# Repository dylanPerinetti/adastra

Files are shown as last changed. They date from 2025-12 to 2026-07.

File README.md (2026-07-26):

# ADASTRA - Data Logger V2 Fusee

### Club NOVA CNAM - CSPACE 2026

Electronique embarquee pour la fusee experimentale du **club NOVA CNAM**, dans le cadre du projet **ADASTRA**.

Le systeme est compose de **deux Arduino Nano independants** :

| Arduino | Role | Fichier source |
|---|---|---|
| **Arduino #1 – Data Logger** | Acquisition capteurs + enregistrement CSV sur micro-SD | `adastra_datalogger-v2.ino` |
| **Arduino #2 – Sequenceur** | Declenchement parachute (solenoide + ressort) | `Sequenceur_Nano.ino` |

---

## Arborescence du depot

```text
adastra/
├── src/
│   ├── adastra_datalogger-v2.ino   # Arduino #1 – Data logger micro-SD
│   ├── Sequenceur_Nano.ino         # Arduino #2 – Sequenceur parachute
│   └── Sequenceur.md               # Documentation sequenceur
│
├── analysis/
│   └── analyse_vol.py              # Analyse post-vol (Python)
│
├── docs/
│   └── schema_branchement.png      # Schema de cablage
│
└── README.md
```

---

## Materiel

### Arduino #1 – Data Logger

| Composant | Role |
|---|---|
| **Arduino Nano** | Microcontroleur data logger |
| **MPU6050** | Accelerometre + gyroscope 6 axes (I2C) |
| **BMP280** | Pression, altitude, temperature (I2C) |
| **HC-SR04** | Capteur ultrason - distance sol (digital) |
| **Module micro-SD (SPI)** | Stockage des donnees de vol |

### Arduino #2 – Sequenceur parachute

| Composant | Role |
|---|---|
| **Arduino Nano** | Microcontroleur sequenceur |
| **Solenoide 24 V** | Liberation du verrou de trappe |
| **MOSFET N logic-level** (IRLZ44N) | Commande de puissance solenoide |
| **Jack de rampe** | Detection decollage (arrachement) |
| **LEDs** | Indication d'etat (arme / tempo / fire / done) |
| **Diode de roue libre** (1N5408) | Protection bobine solenoide |

> Voir [src/Sequenceur.md](src/Sequenceur.md) pour le detail du sequenceur.

---

## Branchement

### Bus I2C (MPU6050 + BMP280)

| Arduino Nano | Module |
|---|---|
| A4 (SDA) | SDA MPU6050 / BMP280 |
| A5 (SCL) | SCL MPU6050 / BMP280 |

### MPU6050

| MPU6050 | Arduino Nano |
|---|---|
| VCC | 5 V *(ou 3.3 V selon module)* |
| GND | GND |
| SDA | A4 |
| SCL | A5 |

Adresse I2C : `0x68`

### BMP280

| BMP280 | Arduino Nano |
|---|---|
| VCC | 3.3 V |
| GND | GND |
| SDA | A4 |
| SCL | A5 |

Adresse I2C : `0x76`

### HC-SR04

| HC-SR04 | Arduino Nano |
|---|---|
| VCC | 5 V |
| GND | GND |
| TRIG | D2 |
| ECHO | D3 |

### Module micro-SD (SPI)

| micro-SD | Arduino Nano |
|---|---|
| VCC | 5 V *(avec regul.)* ou 3.3 V |
| GND | GND |
| CS | D10 |
| MOSI | D11 |
| MISO | D12 |
| SCK | D13 |

---

## Architecture logicielle

```
          ┌──────────┐
          │  SETUP   │
          └────┬─────┘
               │
        ┌──────▼──────┐
        │  Init SD ?  │──Non──▶ mode serie seul
        └──────┬──────┘
               │ Oui
        ┌──────▼──────┐
        │  Init I2C   │  MPU6050 + BMP280
        └──────┬──────┘
               │
        ┌──────▼──────┐
        │   LOOP      │◀────────────────┐
        │  50 Hz      │                 │
        ├─────────────┤                 │
        │ Lecture      │                │
        │ capteurs     │                │
        ├─────────────┤                │
        │ Ligne CSV    │                │
        │ → serie      │                │
        │ → SD         │                │
        └──────┬──────┘                 │
               └────────────────────────┘
```

1. Lecture des capteurs (MPU6050, BMP280, HC-SR04)
2. Construction d'une ligne CSV en memoire
3. Ecriture simultanee sur **serie** et **carte micro-SD**
4. Compensation du temps d'execution pour maintenir ~50 Hz

---

## Format CSV

Le fichier `ADASTRA.CSV` est cree automatiquement sur la carte SD au premier demarrage.

| Colonne | Unite | Description |
|---|---|---|
| `time_ms` | ms | Timestamp (`millis()`) |
| `ax`, `ay`, `az` | m/s² | Accelerations (MPU6050) |
| `gx`, `gy`, `gz` | rad/s | Vitesses angulaires (MPU6050) |
| `pressure_Pa` | Pa | Pression atmospherique (BMP280) |
| `altitude_m` | m | Altitude barometrique (BMP280) |
| `temp_C` | °C | Temperature (BMP280) |
| `distance_cm` | cm | Distance au sol (HC-SR04) |

---

## Librairies Arduino

A installer via le gestionnaire de bibliotheques :

| Librairie | Usage |
|---|---|
| `Adafruit MPU6050` | Accelerometre / gyroscope |
| `Adafruit BMP280` | Pression / altitude |
| `Adafruit Unified Sensor` | Dependance Adafruit |
| `SD` | Lecture / ecriture carte micro-SD |
| `Wire` | Bus I2C *(incluse)* |
| `SPI` | Bus SPI *(incluse)* |

---

## Analyse post-vol (Python)

Le script `analysis/analyse_vol.py` fournit :

- **10 graphiques** : altitude, accelerations (XYZ + norme, m/s² et g), gyroscope (rad/s et °/s + norme), pression / temperature, distance sol, vitesse verticale, taux de montee/descente, dashboard recapitulatif
- **Detection automatique** du decollage, de l'apogee et de l'atterrissage
- **Rapport synthetique** : duree de vol, apogee, acceleration max, pression min/max, temperatures
- **Filtrage Butterworth** passe-bas pour lisser les donnees bruitees
- **Estimation de la vitesse verticale** par integration de l'acceleration

### Dependances Python

```bash
pip install numpy pandas matplotlib scipy
```

### Utilisation

```bash
# Afficher les graphiques (mode interactif)
python analysis/analyse_vol.py --file ADASTRA.CSV

# Sauvegarder les graphiques en PNG
python analysis/analyse_vol.py --file ADASTRA.CSV --save --outdir plots/
```

### Sortie type

```
====================================================
   RAPPORT DE VOL – ADASTRA - Club NOVA CNAM
====================================================
  Duree totale enregistrement : 42.56 s
  Nombre d'echantillons       : 2128
  Frequence moyenne           : 50.0 Hz

  Apogee                      : 312.45 m
  Temps apogee                : 8.72 s
  Acceleration max            : 78.53 m/s² (8.01 g)
  Pression min                : 977.32 hPa
  Pression max                : 1012.87 hPa
  Temperature min / max       : 18.2 / 22.7 °C

  [  Decollage  ]  t = 1.24 s
  [   Apogee    ]  t = 8.72 s
  [Atterrissage ]  t = 38.90 s
====================================================
```

---

## Securite & robustesse

- Stockage non volatile sur micro-SD (pas de perte si coupure)
- Si la carte SD est absente, les donnees restent visibles sur le port serie
- Bus I2C simple et fiable pour les capteurs
- Compensation de la duree de boucle pour une frequence d'echantillonnage stable
- Code minimaliste pour reduire les risques d'erreurs en vol

---

## Evolutions prevues

- Gestion multi-fichiers (index auto par vol)
- Redondance / checksum des donnees
- Calcul d'apogee en temps reel a bord
- Integration avec le sequenceur de recuperation

---

## Site web de l'association

Le site vitrine d'AD ASTRA vit dans un depot separe :
**[dylanPerinetti/adastra-website](https://github.com/dylanPerinetti/adastra-website)** (Laravel).

Il rejoue les enregistrements produits par ce data logger dans un tableau de bord de
telemetrie : altitude, accelerations, vitesse verticale, vitesses angulaires, pression et
temperature, avec detection du decollage, de l'apogee et de l'atterrissage.

Le format CSV decrit plus haut est donc un **contrat entre les deux depots**. Une colonne
renommee ou supprimee ici casse l'affichage la-bas — les colonnes optionnelles
(`sound_speed_ms`, `mag_*_uT`) sont en revanche tolerees.

Le jeu de donnees `analysis/VOL00_test.csv` est duplique dans le depot du site
(`database/seeders/data/`) pour qu'un clone isole dispose de vraies courbes.

---

## Auteurs

Projet developpe par le **club NOVA CNAM**
Data logger par **Dylan Perinetti**

> *« Je ne perds jamais, soit je gagne, soit j'apprends. »* – Nelson Mandela

---

## Projet ADASTRA

Fusee experimentale etudiante – CNAM — CSPACE 2026

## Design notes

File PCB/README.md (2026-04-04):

# PCB Support ADASTRA v2 - Arduino Nano + BMP280 + MPU9250 + SD + HC-SR04

> Adapté pour le projet [ADASTRA (FuséEx)](https://github.com/dylanPerinetti/adastra)
> Club NOVA CNAM — CSPACE 2026
> Firmware : `src/adastra_datalogger-v2.ino`

## Connexions (Pin Mapping)

### Bus I2C (BMP280 + MPU9250)
| Signal | Arduino Nano Pin | BMP280  | MPU9250 |
|---|---|---|---|
| SDA | A4 | SDA | SDA |
| SCL | A5 | SCL | SCL |
| VCC | 3.3V | VCC (3.3V) | — |
| VCC | 5V | — | VCC (5V)|
| GND | GND | GND | GND |
| CSB | — | V3V3 (I2C mode) | — |
| SDO | — | GND (addr 0x76) | — |

> **Note :** Le BMP280 est alimenté en 3.3V, le MPU9250 en 5V (comme dans le code ADASTRA v2).
> **BMP280 6 pins :** VCC, GND, SCL, SDA, CSB (→ V3V3 pour mode I2C), SDO (→ GND pour adresse 0x76).

Pull-ups I2C: 2x 4.7k ohm vers 3.3V (R5 sur SDA, R6 sur SCL)
Condensateur de decouplage: C1 = 100nF sur le rail 3.3V

### Bus SPI (Module SD)
| Signal | Arduino Nano Pin | SD Module |
|---|---|---|
| GND | GND | GND (pin 1) |
| VCC | 5V | VCC (pin 2) |
| MISO | D12 | MISO (pin 3) |
| MOSI | D11 | MOSI (pin 4) |
| SCK | D13 | SCK (pin 5)  |
| CS | D10 | CS (pin 6) |

### Capteur ultrason HC-SR04
| Signal | Arduino Nano Pin | HC-SR04 |
|---|---|---|
| TRIG | D2 | TRIG |
| ECHO | D3 | ECHO |
| VCC | 5V | VCC |
| GND | GND | GND |

> Mesure de la vitesse du son (distance fixe connue, 50 cm par défaut).

### LEDs d'état (4x)
| LED | Arduino Pin | Résistance | Fonction |
|---|---|---|---|
| D1 — LED_SD | D4 | R1 (220Ω)  | Carte SD prête (allumée = OK) |
| D2 — LED_SENSOR | D5 | R2 (220Ω)  | Capteurs initialisés (allumée) |
| D3 — LED_LOG | D6 | R3 (220Ω)  | Clignote à chaque écriture SD |
| D4 — LED_ERROR  | D7 | R4 (220Ω)  | Erreur détectée |

Chaque LED : Dx -> Rx (220 ohm) -> LED -> GND

### Autres
| Composant | Connexion |
|---|---|
| Interrupteur ON/OFF (SW1) | BATT+ -> Switch -> VIN |
| Batterie (J1 JST) | + -> SW1, - -> GND |

## Résumé des pins Arduino Nano utilisées

| Pin  | Fonction |
|---|---|
| D0 | RX (libre) |
| D1 | TX (libre) |
| D2 | HC-SR04 TRIG |
| D3 | HC-SR04 ECHO |
| D4 | LED_SD |
| D5 | LED_SENSOR |
| D6 | LED_LOG |
| D7 | LED_ERROR |
| D8 | — |
| D9 | — |
| D10  | SD CS (SPI) |
| D11  | SD MOSI (SPI) |
| D12  | SD MISO (SPI) |
| D13  | SD SCK (SPI) |
| A4 | SDA (I2C) |
| A5 | SCL (I2C) |
| VIN  | Batterie + |
| 5V | MPU9250, SD, HC-SR04 |
| 3.3V | BMP280 |
| GND  | Commun |

## Dimensions du PCB
- Taille: 80mm x 65mm (largeur x hauteur)
- 4 trous de montage M3 (3.2mm)
- 2 couches (F.Cu / B.Cu)

## Composants
| Ref  | Valeur | Empreinte |
|---|---|---|
| A1 | Arduino Nano v3 | 2x15 pin headers (2.54mm) |
| U1 | BMP280 | 1x6 pin header (2.54mm) |
| U2 | MPU9250 | 1x10 pin header (2.54mm) |
| U3 | SD Module | 1x6 pin header (2.54mm) |
| U4 | HC-SR04 | 1x4 pin header (2.54mm) |
| D1 | LED Green (SD)  | LED 3mm THT |
| D2 | LED Green (SENS)| LED 3mm THT |
| D3 | LED Yellow (LOG)| LED 3mm THT |
| D4 | LED Red (ERROR) | LED 3mm THT |
| R1 | 220 ohm | Axial THT (LED_SD) |
| R2 | 220 ohm | Axial THT (LED_SENSOR) |
| R3 | 220 ohm | Axial THT (LED_LOG) |
| R4 | 220 ohm | Axial THT (LED_ERROR) |
| R5 | 4.7k ohm | Axial THT (I2C SDA pull-up)  |
| R6 | 4.7k ohm | Axial THT (I2C SCL pull-up)  |
| C1 | 100nF | Disc ceramique THT |
| SW1  | ON/OFF Switch | Toggle SPST THT |
| J1 | JST PH 2pin | Connecteur batterie |

## Instructions
1. Ouvrir PCB_Support.kicad_pro dans KiCad 7+
2. Vérifier le schéma (PCB_Support.kicad_sch)
3. Ajuster le routage dans le PCB editor si nécessaire
4. Lancer le DRC (Design Rule Check) avant fabrication
5. Générer les fichiers Gerber pour la production

## Correspondance avec le firmware ADASTRA v2
```
constexpr uint8_t SD_CS_PIN       = 10;   // → U3 pin CS
constexpr uint8_t TRIG_PIN        = 2;    // → U4 pin TRIG
constexpr uint8_t ECHO_PIN        = 3;    // → U4 pin ECHO
constexpr uint8_t LED_SD_PIN      = 4;    // → D1 via R1
constexpr uint8_t LED_SENSOR_PIN  = 5;    // → D2 via R2
constexpr uint8_t LED_LOG_PIN     = 6;    // → D3 via R3
constexpr uint8_t LED_ERROR_PIN   = 7;    // → D4 via R4
```

## Notes
- Les modules breakout se soudent directement sur les pin headers
- Le MPU9250 est alimenté en 5V (module breakout avec régulateur intégré)
- Le BMP280 est alimenté en 3.3V (tension de fonctionnement native, 6 pins : VCC/GND/SCL/SDA/CSB/SDO)
- CSB du BMP280 connecté à V3V3 (active le mode I2C)
- SDO du BMP280 connecté à GND (adresse I2C = 0x76)
- Le HC-SR04 nécessite une distance fixe connue (cible réfléchissante à 50 cm)
- Adresse I2C MPU9250 : 0x68 (AD0 = GND, par défaut)
- Adresse I2C BMP280 : 0x76
- Vérifiez le pinout exact de vos modules breakout avant soudure !

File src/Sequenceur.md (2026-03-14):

# Sequenceur de recuperation - Projet ADASTRA

## Objectif

Systeme de **recuperation par ouverture de trappe** commandee electroniquement, permettant le deploiement du parachute / streamer apres le decollage.

Principe : **verrouillage mecanique** libere par un **solenoide**, puis **ouverture forcee** par **ressort de compression**.

---

## Architecture mecanique

```
     Corps fusee
    ┌───────────────────┐
    │  ┌─────────────┐  │
    │  │   Ressort    │  │  <- comprime entre trappe et butee
    │  │   ~~~~~~     │  │
    │  └──────┬──────┘  │
    │         │         │
    │  ┌──────▼──────┐  │
    │  │   Trappe    │◄─┼── verrou / goupille
    │  └─────────────┘  │         │
    └───────────────────┘         │
                           ┌──────▼──────┐
                           │  Solenoide  │  <- retire la goupille
                           └─────────────┘
```

- La **trappe** est maintenue fermee par un **verrou** (goupille, crochet ou linguet).
- Le **ressort** est comprime entre la trappe et une butee interne.
- Au declenchement, le solenoide **retire la goupille** et le ressort **pousse** la trappe vers l'exterieur.

> Le ressort est a dimensionner selon : frottements, rigidite de la trappe, pression aerodynamique, tolerances mecaniques.
> L'objectif : une ouverture **franche** et **repetable**.

---

## Sequence de fonctionnement

```
  [Sur rampe]          [Decollage]          [Tempo]           [Ouverture]
       │                    │                  │                   │
  Jack insere          Jack arrache       X secondes         Solenoide ON
  Arduino en           Arduino detecte    (parametrable)     Verrou libere
  mode attente         le depart          compte a rebours   Ressort pousse
       │                    │                  │                   │
   WAIT_ARM  ──────▶  WAIT_LAUNCH ──────▶  WAIT_DELAY ──────▶  FIRE ──▶ DONE
```

1. **Preparation sur rampe** : jack insere (D2 = LOW) -> Arduino en mode "attente"
2. **Decollage** : jack arrache (D2 = HIGH) -> detection du depart
3. **Temporisation** : attente de **X secondes** (configurable, defaut 4 s)
4. **Declenchement** : impulsion de 250 ms sur le solenoide via MOSFET
5. **Ouverture** : le ressort ouvre la trappe, etat DONE

---

## Electronique de commande

### Microcontroleur

- **Arduino Nano** (dedie au sequenceur, independant du data logger)

### Schema de commande (MOSFET low-side)

```
  +Batt (24 V) ─────┐
                     │
              ┌──────▼──────┐
              │  Solenoide  │
              └──────┬──────┘
                     │
              ┌──────┤ Diode roue libre (1N5408)
              │      │ (cathode vers +Batt)
              │      │
              │  Drain MOSFET (IRLZ44N)
              │      │
              │  Source ──── GND batt
              │
              Gate ──── 100 Ohm ──── D9 Arduino
              │
              100 kOhm (pull-down vers GND)
```

### Cablage Arduino

| Pin Arduino Nano | Fonction |
|---|---|
| D2 | Entree jack de rampe (INPUT_PULLUP) |
| D7 | LED "ARME" (optionnelle) |
| D8 | LED "TEMPO" (optionnelle) |
| D9 | Sortie MOSFET gate (commande solenoide) |
| D10 | LED "DONE" (optionnelle) |
| LED_BUILTIN (D13) | LED statut / FIRE |

> **Masse commune obligatoire** : le GND Arduino doit etre relie au GND du pack solenoide.

### LEDs d'etat

| LED | Etat | Comportement |
|---|---|---|
| LED integree (D13) | WAIT_ARM | Clignotement lent (800 ms) |
| LED ARME (D7) | WAIT_LAUNCH | Clignotement moyen (600 ms) |
| LED TEMPO (D8) | WAIT_DELAY | Clignotement rapide (250 ms) |
| LED integree (D13) | FIRE | Fixe ON pendant impulsion |
| LED DONE (D10) | DONE | Fixe ON |

---

## Alimentation

### Arduino Nano

- **Pile 9 V** (via Vin ou jack barrel)

> Note : les piles 9 V classiques ont une capacite limitee. A valider par essais (stabilite 5 V, vibrations, temperature, duree d'armement sur rampe).

### Solenoide

- **2x piles 12 V en serie** (~24 V) pour un solenoide annonce 24 V.

> Les piles 12 V type A23 (telecommandes) ont un courant disponible limite.
> Mesurer le courant du solenoide et verifier que les piles peuvent fournir l'impulsion sans s'effondrer en tension.
> Alternative si necessaire : pack Li-ion / LiPo + regulation.

---

## Parametres logiciels

Definis dans `Sequenceur_Nano.ino`, facilement modifiables :

| Parametre | Valeur par defaut | Description |
|---|---|---|
| `DELAY_MS` | 4000 ms | Temporisation post-decollage |
| `PULSE_MS` | 250 ms | Duree impulsion solenoide |
| `DEBOUNCE_MS` | 150 ms | Anti-rebond lecture jack |
| `USE_EXTERNAL_LEDS` | 1 | Activer LEDs externes (0 = LED integree seule) |

---

## Materiel et liens

### Solenoide 24 V

- Type : solenoide poussoir / tirette, course ~10 mm
- Lien : https://amzn.eu/d/0choRAVG

### MOSFET N logic-level

- Reference : **IRLZ44N** (Vgs(th) < 5 V, 55 V, 47 A)
- Lien : https://amzn.eu/d/5bYtHvN

### Diode de roue libre

- Reference : **1N5408** (3 A, 1000 V) ou equivalent
- Lien : https://amzn.eu/d/gT8MMEM

### Piles 12 V (x2 en serie)

- Type : A23 / GP23A / LRV08 (12 V alcaline)
- Lien : https://amzn.eu/d/5VWfVjR

### LEDs

- Kit LEDs 5 mm assorties (rouge, vert, jaune)
- Lien : https://amzn.eu/d/dN9rPSL

### Resistances

- 100 Ohm (gate serie MOSFET) + 100 kOhm (pull-down gate)
- Kit resistances : https://amzn.eu/d/2kxkV0U

### Mecanique

- Ressort de compression (a dimensionner selon effort requis)
- Verrou / goupille + guidage (eviter les coincements)
- Trappe + charniere / axe (selon conception fusee)
- Jack de rampe (contact d'armement / detection decollage)

---

## Fichier source

- **`src/Sequenceur_Nano.ino`**

Le code gere :
- Detection d'insertion / arrachement du jack (anti-rebond)
- Machine a etats (WAIT_ARM -> WAIT_LAUNCH -> WAIT_DELAY -> FIRE -> DONE)
- Impulsion solenoide via MOSFET
- Clignotement LEDs non-bloquant selon l'etat
- Securite : MOSFET OFF au demarrage, declenchement unique (re-armer = couper l'alim)

---

## Tests et securite

- Faire **minimum 20-50 tests au sol** (ouverture repetee) avant vol
- Ajouter un **interrupteur d'armement** physique (SAFE / ARM) en serie sur l'alimentation
- Proteger le circuit et securiser les cables (vibrations en vol)
- Verifier la tenue mecanique du verrou sous acceleration (phase propulsee)
- Chronometrer la temporisation reelle vs parametree

---

**Signature :** Dylan Perinetti - *NovaCnam* - Projet **ADASTRA**

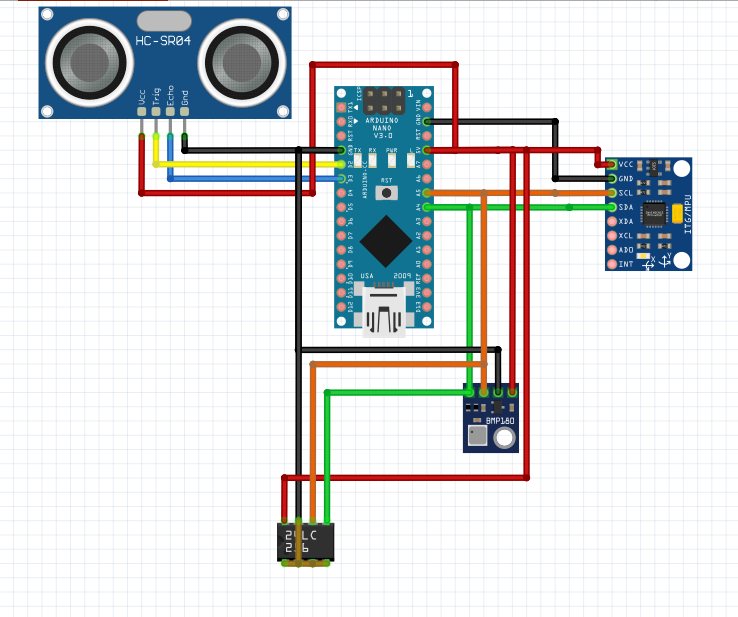
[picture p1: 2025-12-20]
docs/schema_branchement.png

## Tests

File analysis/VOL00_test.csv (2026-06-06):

time_ms | ax | ay | az | gx | gy | gz | pressure_Pa | altitude_m | temp_C | sound_speed_ms | mag_x_uT | mag_y_uT | mag_z_uT
412 | -0.585 | -0.391 | 10.186 | -0.052 | 0.038 | 0.009 | 101322.2 | 0.10 | 19.50 | 343.07 | 21.49 | 0.53 | 40.47
434 | 0.264 | -0.015 | 9.426 | -0.043 | 0.018 | 0.014 | 101321.6 | 0.00 | 19.56 | 343.53 | 21.91 | -0.26 | 39.79
452 | -0.154 | -0.244 | 9.647 | 0.022 | 0.107 | 0.012 | 101324.7 | 0.49 | 19.49 | 343.74 | 21.50 | -0.49 | 40.39
474 | 0.035 | 0.066 | 9.903 | 0.027 | -0.033 | -0.035 | 101317.7 | 0.70 | 19.53 | 341.54 | 22.04 | 0.17 | 40.38
496 | -0.260 | 0.290 | 10.408 | -0.032 | -0.014 | -0.014 | 101323.3 | 0.00 | 19.51 | 342.65 | 22.35 | 0.43 | 40.48
516 | -0.276 | 0.149 | 9.357 | -0.010 | -0.064 | 0.026 | 101327.1 | 0.11 | 19.48 | 343.46 | 22.10 | 0.38 | 39.81
535 | -0.141 | 0.004 | 10.005 | -0.019 | -0.060 | -0.011 | 101322.6 | 0.38 | 19.53 | 341.31 | 21.94 | -0.25 | 39.95
553 | -0.113 | 0.390 | 9.448 | -0.050 | 0.020 | -0.040 | 101328.7 | 0.00 | 19.45 | 343.84 | 21.88 | -0.57 | 39.80
572 | 0.022 | -0.159 | 9.232 | 0.012 | -0.030 | 0.013 | 101322.9 | 0.19 | 19.58 | 343.22 | 21.86 | -0.61 | 40.11
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

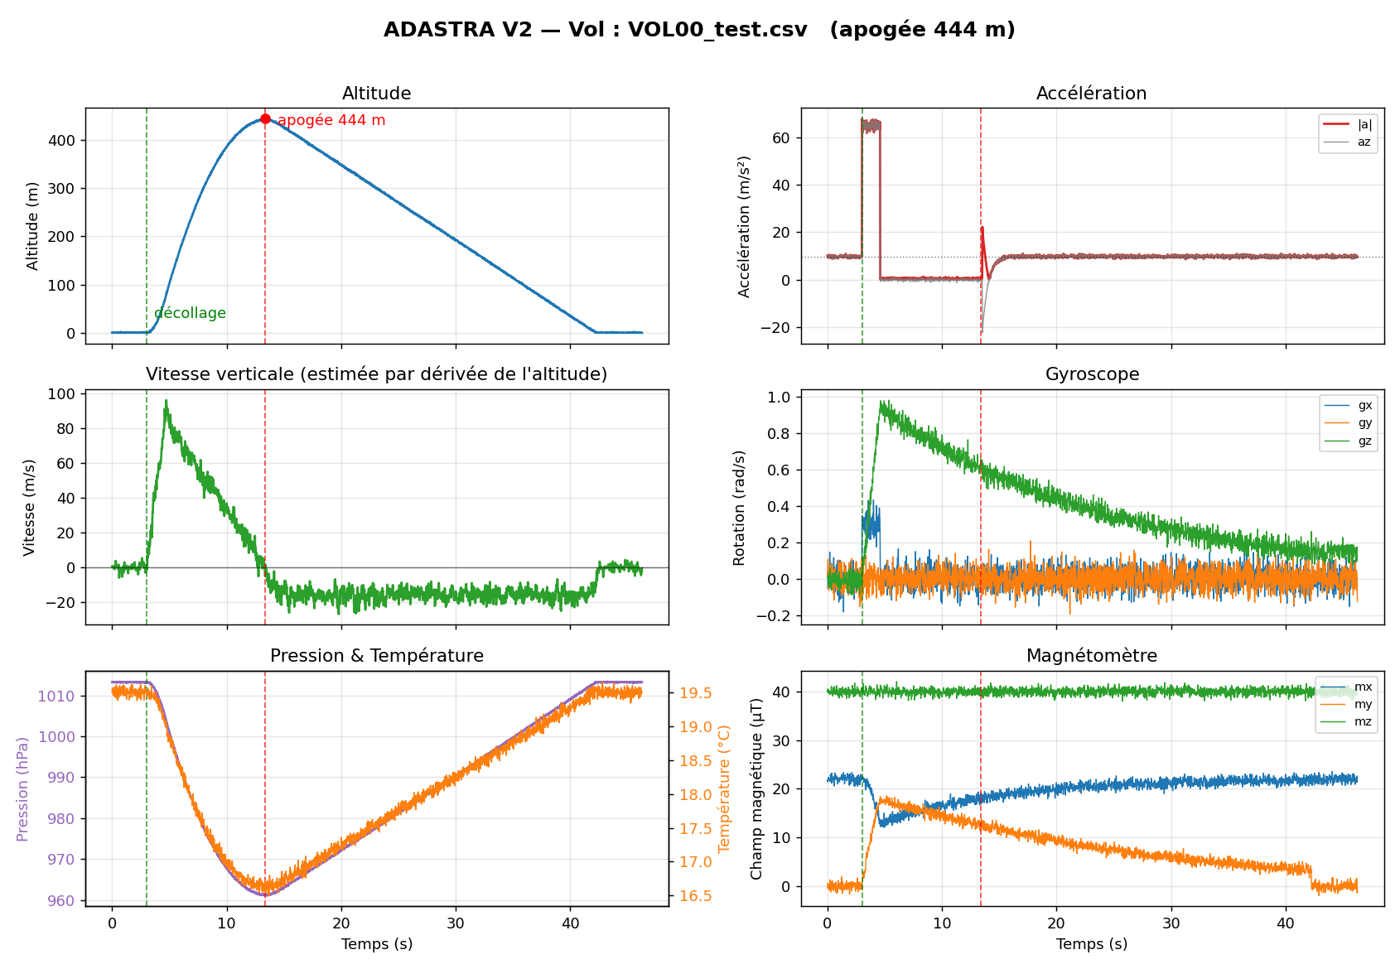
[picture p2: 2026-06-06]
analysis/VOL00_test_analyse.png

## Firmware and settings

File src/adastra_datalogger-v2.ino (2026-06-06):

/****************************************************
 *  ADASTRA (FuséEx) - Data Logger V2  (MPU9250)
 *  Club NOVA CNAM pour le CSPACE 2026
 *
 *  Capteurs :
 *   - MPU9250 (Accél.+Gyro+Magnéto) → I2C (SDA=A4, SCL=A5), VCC=3.3V*, GND
 *   - BMP280  (Press./Alt.)         → I2C (SDA=A4, SCL=A5), VCC=3.3V, GND
 *   - HC-SR04 (Vitesse son)         → TRIG=D2, ECHO=D3, VCC=5V, GND
 *
 *   * Attention : le chip MPU9250 est 3.3V. La plupart des modules
 *     (GY-9250 / GY-91) intègrent un régulateur + adaptateur de niveau
 *     et acceptent 3.3-5V — vérifier votre carte avant d'alimenter en 5V.
 *
 *  Stockage :
 *   - Carte micro-SD (SPI) → CS=D10, MOSI=D11, MISO=D12, SCK=D13,
 *                             VCC=5V, GND
 *   - Version "vol" : fichier gardé ouvert + flush périodique + rotation
 *     de fichier (VOL00.CSV, VOL01.CSV, ...) + reconnexion automatique.
 *
 *  LEDs d'état :
 *   - LED_SD     (D4) : carte SD prête + fichier ouvert (allumée = OK)
 *   - LED_SENSOR (D5) : capteurs initialisés (allumée = OK)
 *   - LED_LOG    (D6) : "heartbeat" — bascule à chaque flush (~250 ms)
 *   - LED_ERROR  (D7) : erreur (capteur fatal, ou SD absente/éjectée)
 *
 *  Bibliothèque IMU : "MPU9250" by Bolder Flight Systems
 *    (Arduino IDE → Gérer les bibliothèques → chercher "Bolder Flight MPU9250")
 *
 *  Auteur : Dylan Perinetti
 ****************************************************/

#include <Arduino.h>
#include <Wire.h>
#include <SPI.h>
#include <SD.h>
#include <MPU9250.h>            // Bolder Flight Systems
#include <Adafruit_BMP280.h>
#include <Adafruit_Sensor.h>

/* ===================== CONFIG ===================== */

constexpr uint8_t SD_CS_PIN       = 10;            // Chip select micro-SD (Nano = D10)
constexpr uint8_t TRIG_PIN        = 2;
constexpr uint8_t ECHO_PIN        = 3;

constexpr uint8_t MPU9250_ADDR    = 0x68;          // 0x68 (AD0=GND) ou 0x69 (AD0=VCC)

/* --- LEDs d'état --- */
constexpr uint8_t LED_SD_PIN      = 4;             // SD prête (allumée = OK)
constexpr uint8_t LED_SENSOR_PIN  = 5;             // Capteurs OK (allumée = OK)
constexpr uint8_t LED_LOG_PIN     = 6;             // Heartbeat (bascule à chaque flush)
constexpr uint8_t LED_ERROR_PIN   = 7;             // Erreur détectée

constexpr float   SEA_LEVEL_HPA   = 1013.25;       // hPa (à ajuster le jour du vol)
constexpr unsigned long LOG_PERIOD_MS = 20;         // ~50 Hz
constexpr unsigned long ECHO_TIMEOUT_US = 30000;    // timeout pulseIn (µs)

/* --- HC-SR04 : distance fixe connue --- */
constexpr float FIXED_DISTANCE_CM = 50.0f;          // distance fixe capteur-cible (cm) — À AJUSTER

/* --- Stockage "vol" --- */
constexpr unsigned long FLUSH_PERIOD_MS    = 250;   // commit sur la carte tous les 250 ms
constexpr unsigned long SD_RETRY_PERIOD_MS = 1000;  // tentative de reconnexion SD
static const char LOG_PREFIX[] = "VOL";             // → VOL00.CSV, VOL01.CSV, ...

// En-tête CSV (utilisé pour le fichier ET la sortie série, défini une seule fois)
#define CSV_HEADER "time_ms,ax,ay,az,gx,gy,gz,pressure_Pa,altitude_m,temp_C,sound_speed_ms,mag_x_uT,mag_y_uT,mag_z_uT"

/* ===================== OBJETS ===================== */

MPU9250          mpu(Wire, MPU9250_ADDR);          // IMU 9 axes sur le bus I2C
Adafruit_BMP280  bmp;

File          logFile;                  // fichier de log gardé ouvert pendant tout le vol
char          logFilename[13] = "";     // nom 8.3 choisi (ex: "VOL00.CSV")

bool sdReady    = false;   // carte SD + fichier ouvert ?
bool sensorsOk  = false;   // capteurs initialisés ?

unsigned long lastFlushMs   = 0;
unsigned long lastSdRetryMs = 0;
bool          logLedState   = false;    // état courant du heartbeat LED_LOG

/* ===================== HC-SR04 ===================== */
// Distance fixe connue → on mesure le temps aller-retour
// pour en déduire la vitesse de propagation du signal (m/s).

float readSoundSpeed() {
  digitalWrite(TRIG_PIN, LOW);
  delayMicroseconds(2);
  digitalWrite(TRIG_PIN, HIGH);
  delayMicroseconds(10);
  digitalWrite(TRIG_PIN, LOW);

  unsigned long duration_us = pulseIn(ECHO_PIN, HIGH, ECHO_TIMEOUT_US);
  if (duration_us == 0) return 0.0f;            // pas d'écho reçu

  // vitesse = 2 * distance / temps   (aller-retour)
  // distance en m, temps en s
  float distance_m = FIXED_DISTANCE_CM / 100.0f;
  float time_s     = duration_us / 1000000.0f;
  return (2.0f * distance_m) / time_s;           // m/s
}

/* ===================== STOCKAGE SD ===================== */

// Cherche le premier nom de fichier libre (VOL00.CSV .. VOL99.CSV),
// l'ouvre et écrit l'en-tête CSV. Renvoie true si OK.
bool startNewLog() {
  for (uint8_t i = 0; i < 100; i++) {
    snprintf(logFilename, sizeof(logFilename), "%s%02u.CSV", LOG_PREFIX, (unsigned)i);
    if (!SD.exists(logFilename)) {
      logFile = SD.open(logFilename, FILE_WRITE);
      if (!logFile) return false;
      logFile.println(F(CSV_HEADER));
      logFile.flush();
      return true;
    }
  }
  // Les 100 noms sont pris : on rouvre le dernier en ajout
  logFile = SD.open(logFilename, FILE_WRITE);
  return (bool)logFile;
}

// Rouvre le fichier courant en mode ajout (après une reconnexion).
// Ne réécrit PAS l'en-tête : on continue le même vol.
bool reopenLog() {
  logFile = SD.open(logFilename, FILE_WRITE);   // FILE_WRITE = ajout
  return (bool)logFile;
}

// Bascule l'état "logging OK" / "erreur SD" et pilote les LEDs.
void setSdOk(bool ok) {
  sdReady = ok;
  digitalWrite(LED_SD_PIN,    ok ? HIGH : LOW);
  digitalWrite(LED_ERROR_PIN, ok ? LOW  : HIGH);
}

/* ===================== SETUP ===================== */

void setup() {
  Serial.begin(115200);
  Wire.begin();

  pinMode(TRIG_PIN, OUTPUT);
  pinMode(ECHO_PIN, INPUT);

  /* --- LEDs --- */
  pinMode(LED_SD_PIN,     OUTPUT);
  pinMode(LED_SENSOR_PIN, OUTPUT);
  pinMode(LED_LOG_PIN,    OUTPUT);
  pinMode(LED_ERROR_PIN,  OUTPUT);

  // Toutes éteintes au départ
  digitalWrite(LED_SD_PIN,     LOW);
  digitalWrite(LED_SENSOR_PIN, LOW);
  digitalWrite(LED_LOG_PIN,    LOW);
  digitalWrite(LED_ERROR_PIN,  LOW);

  /* --- Carte micro-SD --- */
  if (SD.begin(SD_CS_PIN) && startNewLog()) {
    setSdOk(true);                                // LED_SD allumée, LED_ERROR éteinte
    Serial.print(F("SD OK -> "));
    Serial.println(logFilename);
  } else {
    setSdOk(false);                               // LED_ERROR allumée (erreur SD visible)
    Serial.println(F("WARN: SD indisponible — donnees serie uniquement"));
  }
  lastFlushMs   = millis();
  lastSdRetryMs = millis();

  /* --- MPU9250 --- */
  // begin() renvoie un statut : > 0 = OK, < 0 = erreur
  int imuStatus = mpu.begin();
  if (imuStatus < 0) {
    Serial.print(F("ERR: MPU9250 introuvable (status="));
    Serial.print(imuStatus);
    Serial.println(F(")"));
    digitalWrite(LED_ERROR_PIN, HIGH);
    while (true) delay(500);
  }
  // Pleines échelles équivalentes à l'ancienne config MPU6050
  mpu.setAccelRange(MPU9250::ACCEL_RANGE_16G);     // ±16 g
  mpu.setGyroRange(MPU9250::GYRO_RANGE_2000DPS);   // ±2000 °/s
  mpu.setDlpfBandwidth(MPU9250::DLPF_BANDWIDTH_20HZ); // ~21 Hz (valeur la plus proche)
  // SRD : 1000 Hz / (1 + srd). srd=19 → 50 Hz interne (cohérent avec ~50 Hz de log)
  mpu.setSrd(19);

  /* --- BMP280 --- */
  if (!bmp.begin(0x76)) {
    Serial.println(F("ERR: BMP280 introuvable"));
    digitalWrite(LED_ERROR_PIN, HIGH);
    while (true) delay(500);
  }
  bmp.setSampling(Adafruit_BMP280::MODE_NORMAL,
                  Adafruit_BMP280::SAMPLING_X2,   // température
                  Adafruit_BMP280::SAMPLING_X16,  // pression
                  Adafruit_BMP280::FILTER_X16,
                  Adafruit_BMP280::STANDBY_MS_1);

  sensorsOk = true;
  digitalWrite(LED_SENSOR_PIN, HIGH);             // Capteurs OK → LED allumée

  Serial.println(F("================================="));
  Serial.println(F("  ADASTRA V2 - DATA LOGGER PRET"));
  Serial.println(F("  Club NOVA CNAM — micro-SD"));
  Serial.print(F("  Distance fixe HC-SR04 : "));
  Serial.print(FIXED_DISTANCE_CM);
  Serial.println(F(" cm"));
  Serial.println(F("================================="));

  // En-tête série (même format que le CSV)
  Serial.println(F(CSV_HEADER));
}

/* ===================== LOOP ===================== */

void loop() {
  unsigned long t0 = millis();

  /* --- Lecture capteurs --- */
  mpu.readSensor();                                // met à jour accél., gyro et magnéto

  float ax = mpu.getAccelX_mss();                  // m/s²
  float ay = mpu.getAccelY_mss();
  float az = mpu.getAccelZ_mss();
  float gx = mpu.getGyroX_rads();                  // rad/s
  float gy = mpu.getGyroY_rads();
  float gz = mpu.getGyroZ_rads();
  float mx = mpu.getMagX_uT();                     // µT
  float my = mpu.getMagY_uT();
  float mz = mpu.getMagZ_uT();

  float pressure   = bmp.readPressure();           // Pa
  float altitude   = bmp.readAltitude(SEA_LEVEL_HPA); // m
  float tempC      = bmp.readTemperature();         // °C

  float soundSpeed = readSoundSpeed();              // m/s (0 si pas d'écho)

  /* --- Construire la ligne CSV --- */
  char line[220];
  snprintf(line, sizeof(line),
    "%lu,%.3f,%.3f,%.3f,%.3f,%.3f,%.3f,%.1f,%.2f,%.2f,%.2f,%.2f,%.2f,%.2f",
    t0,
    ax, ay, az,
    gx, gy, gz,
    pressure, altitude, tempC,
    soundSpeed,
    mx, my, mz);

  /* --- Sortie série (toujours, même sans carte) --- */
  Serial.println(line);

  /* --- Écriture carte SD (fichier gardé ouvert) --- */
  if (sdReady) {
    size_t n = logFile.println(line);
    if (n == 0) {
      // Écriture rejetée → carte probablement éjectée
      logFile.close();
      setSdOk(false);                              // LED_ERROR allumée
      Serial.println(F("ERR: ecriture SD echouee (carte ejectee ?)"));
      lastSdRetryMs = millis();
    } else if (millis() - lastFlushMs >= FLUSH_PERIOD_MS) {
      logFile.flush();                             // commit périodique sur la carte
      lastFlushMs = millis();
      logLedState = !logLedState;                  // heartbeat visible
      digitalWrite(LED_LOG_PIN, logLedState);
    }
  } else {
    // Pas de SD : tentative de reconnexion périodique
    if (millis() - lastSdRetryMs >= SD_RETRY_PERIOD_MS) {
      lastSdRetryMs = millis();
      if (SD.begin(SD_CS_PIN) && (logFilename[0] ? reopenLog() : startNewLog())) {
        setSdOk(true);                             // LED_SD allumée, LED_ERROR éteinte
        Serial.print(F("SD (re)connectee -> "));
        Serial.println(logFilename);
        lastFlushMs = millis();
      }
    }
  }

  /* --- Compenser le temps d'exécution pour garder ~50 Hz --- */
  unsigned long elapsed = millis() - t0;
  if (elapsed < LOG_PERIOD_MS) {
    delay(LOG_PERIOD_MS - elapsed);
  }
}

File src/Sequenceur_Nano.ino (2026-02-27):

/*
  Sequenceur_Nano.ino - Séquenceur de trappe (solénoïde + ressort)
  DylanPerineti - NovaCnam - Projet ADASTRA

  Câblage :
  - Jack de rampe sur D2 : jack inséré => D2 = LOW (vers GND)
                           jack arraché => D2 = HIGH (pull-up)
  - MOSFET (gate) sur D9 : D9 HIGH => solénoïde alimenté (impulsion)
  - Masse commune obligatoire entre Arduino et alim solénoïde

  Gestion LEDs d'états :
  - Par défaut, le code gère des LEDs externes (facultatif) + la LED intégrée.
  - Si tu n'as qu'une seule LED (celle de la Nano), mets USE_EXTERNAL_LEDS à 0.

  Etats :
  1) WAIT_ARM      : attente insertion jack (pas armé)
  2) WAIT_LAUNCH   : armé, attente décollage (jack arraché)
  3) WAIT_DELAY    : temporisation X secondes
  4) FIRE          : impulsion solénoïde
  5) DONE          : déclenchement terminé
*/

#include <Arduino.h>

// ===================== CONFIG =====================
const uint8_t PIN_JACK = 2;   // entrée jack (D2)
const uint8_t PIN_FIRE = 9;   // sortie vers MOSFET gate (D9)

// Paramètres à ajuster
const unsigned long DELAY_MS    = 4000;  // X secondes après décollage
const unsigned long PULSE_MS    = 250;   // durée d'impulsion solénoïde
const unsigned long DEBOUNCE_MS = 150;   // anti-rebond jack

// ----- LEDs d'états -----
#define USE_EXTERNAL_LEDS 1

#if USE_EXTERNAL_LEDS
// Exemple de pins dispo sur un Nano (adaptables à ton câblage)
// (Sur ton schéma, un header semble sortir D7/D8/D9/D10 : on évite D9 car c'est FIRE)
const uint8_t PIN_LED_ARMED  = 7;   // LED "ARMÉ"
const uint8_t PIN_LED_DELAY  = 8;   // LED "TEMPO"
const uint8_t PIN_LED_DONE   = 10;  // LED "DONE"
#endif

const uint8_t PIN_LED_FIRE = LED_BUILTIN; // LED intégrée = "FIRE/STATUS"
// ==================================================


// ===================== ETATS ======================
enum State : uint8_t { WAIT_ARM, WAIT_LAUNCH, WAIT_DELAY, FIRE, DONE };
State state = WAIT_ARM;

unsigned long t0 = 0;            // timer général (départ selon état)
unsigned long tBlink = 0;        // timer clignotement
bool blinkLevel = false;         // niveau de clignotement

// Lecture stable (anti-rebond simple) : "expectedHigh=true" attend HIGH, sinon attend LOW
static bool readJackStable(bool expectedHigh, unsigned long stableMs) {
  unsigned long start = millis();
  while (millis() - start < stableMs) {
    if (digitalRead(PIN_JACK) != (expectedHigh ? HIGH : LOW)) return false;
  }
  return true;
}

// Mise à jour LEDs en fonction de l'état + clignotements non-bloquants
static void updateLeds() {
  const unsigned long now = millis();

  // Périodes de blink selon état (ms). 0 = pas de blink (LED fixe)
  unsigned long period = 0;
  bool armedOn = false;
  bool delayOn = false;
  bool fireOn  = false;
  bool doneOn  = false;

  switch (state) {
    case WAIT_ARM:
      // Pas armé : tout OFF, sauf éventuellement blink lent sur LED intégrée
      period = 800; // blink lent intégré
      fireOn = blinkLevel;
      break;

    case WAIT_LAUNCH:
      // Armé, attente décollage : LED ARMÉ clignote lentement
      period = 600; // ~1,6 Hz
      armedOn = blinkLevel;
      break;

    case WAIT_DELAY:
      // Temporisation : LED TEMPO clignote plus vite
      period = 250; // 4 Hz
      delayOn = blinkLevel;
      break;

    case FIRE:
      // Déclenchement : LED FIRE fixe ON pendant l'impulsion
      fireOn = true;
      break;

    case DONE:
      // Terminé : LED DONE fixe ON
      doneOn = true;
      break;
  }

  // Gestion du blinkLevel (non-bloquant)
  if (period > 0) {
    if (now - tBlink >= period) {
      tBlink = now;
      blinkLevel = !blinkLevel;
    }
  } else {
    // pas de blink => niveau cohérent (OFF par défaut)
    blinkLevel = false;
  }

  // Appliquer sorties LED
#if USE_EXTERNAL_LEDS
  digitalWrite(PIN_LED_ARMED, armedOn ? HIGH : LOW);
  digitalWrite(PIN_LED_DELAY, delayOn ? HIGH : LOW);
  digitalWrite(PIN_LED_DONE,  doneOn  ? HIGH : LOW);
#endif
  digitalWrite(PIN_LED_FIRE,  fireOn  ? HIGH : LOW);
}

// Changement d'état (centralisé)
static void setState(State s) {
  state = s;
  // Reset blink à chaque changement d'état pour un feedback clair
  tBlink = millis();
  blinkLevel = false;
  updateLeds();
}

// ===================== SETUP/LOOP =================
void setup() {
  pinMode(PIN_JACK, INPUT_PULLUP);

  pinMode(PIN_FIRE, OUTPUT);
  digitalWrite(PIN_FIRE, LOW); // sécurité

  pinMode(PIN_LED_FIRE, OUTPUT);
  digitalWrite(PIN_LED_FIRE, LOW);

#if USE_EXTERNAL_LEDS
  pinMode(PIN_LED_ARMED, OUTPUT);
  pinMode(PIN_LED_DELAY, OUTPUT);
  pinMode(PIN_LED_DONE,  OUTPUT);
  digitalWrite(PIN_LED_ARMED, LOW);
  digitalWrite(PIN_LED_DELAY, LOW);
  digitalWrite(PIN_LED_DONE,  LOW);
#endif

  setState(WAIT_ARM);
}

void loop() {
  updateLeds();

  const int jack = digitalRead(PIN_JACK); // LOW = jack présent, HIGH = jack arraché

  switch (state) {
    case WAIT_ARM:
      // On passe "armé" uniquement si le jack est présent de façon stable
      if (jack == LOW && readJackStable(false, DEBOUNCE_MS)) {
        setState(WAIT_LAUNCH);
      }
      break;

    case WAIT_LAUNCH:
      // Décollage : jack arraché (passe à HIGH de façon stable)
      if (jack == HIGH && readJackStable(true, DEBOUNCE_MS)) {
        t0 = millis();
        setState(WAIT_DELAY);
      }
      break;

    case WAIT_DELAY:
      if (millis() - t0 >= DELAY_MS) {
        // Impulsion sur solénoïde via MOSFET
        digitalWrite(PIN_FIRE, HIGH);
        t0 = millis();
        setState(FIRE);
      }
      break;

    case FIRE:
      if (millis() - t0 >= PULSE_MS) {
        digitalWrite(PIN_FIRE, LOW);
        setState(DONE);
      }
      break;

    case DONE:
      // Déclenchement unique. Pour re-armer : couper/remettre l'alimentation.
      break;
  }
}

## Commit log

2025-12-20 Add EEPROM reader and CSV export functionality
    This code reads data from an EEPROM and exports it in CSV format. It defines a structure for log data and implements functions to read and print the data.
2025-12-20 Add flight analysis script for ADASTRA
    This script analyzes flight data from a CSV file, generating plots for altitude, vertical acceleration, and gyroscope data, while also calculating and displaying the apogee information.
2026-02-27 Update file path and remove compliance note
    Updated file path for Arduino IDE code and removed a compliance note.
2026-02-27 Update file path for Arduino IDE sequenceur code
2026-02-27 Add Sequenceur_Nano.ino for solenoid control
    Initial implementation of the Sequenceur Nano project for controlling a solenoid with state management and LED indicators.
2026-02-27 Add LED product link to Sequenceur.md
    Added a link to a LED product for reference.
2026-02-27 Simplify circuit protection instructions
    Removed redundancy in circuit protection recommendation.
2026-03-14 V2 : migration EEPROM → micro-SD, refonte analyse Python, docs mises à jour
    - adastra_datalogger-v1.ino : stockage micro-SD (CSV), suppression EEPROM,
    config MPU6050/BMP280, compensation boucle 50 Hz
    - analyse_vol.py : 6 graphiques, filtrage Butterworth, détection événements
    (décollage/apogée/atterrissage), rapport synthétique, CLI argparse
    - README.md : 2 Arduino (data logger + séquenceur), arborescence nettoyée
    - Sequenceur.md : schémas ASCII, tableaux câblage/LEDs/paramètres, liens Amazon
    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
2026-03-14 Rename v1→v2, ajout 4 courbes Python + dashboard
    - Rename adastra_datalogger-v1.ino → adastra_datalogger-v2.ino
    - analyse_vol.py : +4 graphiques (accel en G, norme gyro °/s,
    taux montée/descente, dashboard 6 panneaux) → 10 courbes au total
    - README.md : refs mises à jour (v2, 10 graphiques)
2026-03-22 feat: ajout LEDs d'état + HC-SR04 vitesse du son à distance fixe
    [adastra_datalogger-v2.ino]
2026-03-22 docs: ajout pins de branchement dans l'en-tête
2026-03-22 docs: ajout tensions d'alimentation (3.3V/5V) dans l'en-tête
2026-06-06 Replace MPU6050 with MPU9250 and enhance logging
    Updated data logger to support MPU9250 sensor and improved SD file handling.
    [adastra_datalogger-v2.ino]
2026-07-26 docs: lier le site vitrine et exclure website/ du depot firmware
    Le site vitrine de l'association a ete developpe pendant cette session et
    publie dans son propre depot, dylanPerinetti/adastra-website.
    Le dossier website/ reste present en local mais porte son propre .git :
    le suivre ici creerait un lien de sous-module casse (dossier vide au
    clonage), git emet d'ailleurs un avertissement explicite. Il est donc
    ignore, au meme titre que la configuration locale .claude/.
    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
